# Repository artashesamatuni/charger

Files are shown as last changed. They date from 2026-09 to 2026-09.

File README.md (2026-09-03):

# Single-phase AC EVSE prototype

Engineering baseline for a European Mode 3 EV supply equipment prototype:

- 230 V AC, single phase
- 32 A maximum (7.4 kW nominal), configurable 6–32 A
- permanently attached cable with Type 2 vehicle connector (Case C)
- ESP32 controller with Wi-Fi
- IEC 61851 control pilot

Engineering documents:

- [System baseline](docs/system-baseline.md): external I/O, safety concept, self-tests, charging state machine, hardware architecture, and firmware partitioning.
- [System requirements](docs/system-requirements.md): traceable, verifiable product requirements.
- [Preliminary hazard analysis](docs/hazard-analysis.md): design FMEA and required independent safety paths.
- [Architecture and interface specification](docs/architecture-and-interfaces.md): frozen product options, subsystem partitioning, communications, UI, and schematic-sheet plan.
- [Thermal derating algorithm](docs/thermal-derating.md): sensor validation, current limiting, shutdown/recovery behavior, and environmental test matrix.\n- [Rev A controller schematic specification](hardware/rev-a/controller-schematic-spec.md): ESP32-S3, BRCS01C, watchdog, hardwired contactor inhibit, self-test, and KiCad sheet plan.\n- [Rev A preliminary BOM](hardware/rev-a/preliminary-bom.csv): selected, provisional, and open controller components.

> This repository is an engineering prototype, not certified equipment. Mains testing requires appropriate competence, isolation, protection, enclosure, and test equipment. Do not connect a vehicle or public supply until the safety circuits and fault responses have been independently reviewed and tested.

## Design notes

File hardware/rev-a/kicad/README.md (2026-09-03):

# KiCad schematic — Rev A

## Open the schematic

Open `evse-controller-rev-a.sch` in KiCad 8 or 9. It is stored in the KiCad legacy schematic format so it remains human-reviewable in GitHub. KiCad will offer to convert it; save the converted result as `.kicad_sch`.

## Current content

- protected 24 V input;
- provisional 5.5 V, 5 V RDC and 3.3 V power stages;
- ESP32-S3-WROOM-1;
- BRCS01C-05-H1 connector;
- fail-safe pull-up interpretation for both trip outputs;
- hardware safety-latch functional block;
- TPS3430-Q1 watchdog functional block;
- Type 2 CP/PP connector;
- future contactor interface, with contactor and coil driver DNP.

## Verification status

The text structure is balanced and contains 16 component blocks and 52 wire records. KiCad and ERC were not available on the authoring host, so graphical import, symbol resolution and ERC are **not yet verified**.

Do not assign PCB footprints or order a PCB from this draft. Several complex devices are represented as named functional connector blocks while their exact implementation is refined in the adjacent sheet-definition documents.

## Required KiCad review

1. Open and convert the legacy file.
2. Confirm that `RF_Module:ESP32-S3-WROOM-1` resolves with the installed symbol library.
3. Inspect power pin visibility and pin mapping.
4. Replace each named functional connector block with the final manufacturer symbol.
5. Add no-connect flags intentionally.
6. Run ERC with custom safety rules.
7. Export PDF and visually inspect every net and junction.

The contactor will be added only after its exact model and coil interface are frozen.

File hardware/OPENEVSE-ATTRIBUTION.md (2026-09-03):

# OpenEVSE design-basis attribution

Parts of the EVSE controller architecture and subsequent hardware implementation are adapted from **OpenEVSE_PLUS v6.5.1**.

- Upstream project: https://github.com/OpenEVSE/OpenEVSE_PLUS
- Reference revision inspected: repository tree `b9f101e9b7bae0846ca72638b9d22bb8c49298d5`
- Reference schematic: `OpenEVSE_PLUS_v6.5.1/OpenEVSE_PLUS_v6.5.1.sch`
- Upstream hardware license: Creative Commons Attribution-ShareAlike 3.0 (CC BY-SA 3.0)
- License text: https://creativecommons.org/licenses/by-sa/3.0/

## Functions used as a design basis

- ±12 V control-pilot generation;
- pilot ADC/state measurement;
- proximity-pilot measurement;
- residual-current/GFCI self-test pattern;
- separate relay commands and feedback/weld detection;
- current-transformer measurement;
- power-on safe defaults.

## Intentional differences

- ESP32-S3 at 3.3 V replaces ATmega328P at 5 V.
- BRCS01C-05-H1 and an external Type A RCD replace the OpenEVSE GFCI implementation.
- EU single-phase Type 2, TN-S/TN-C-S and L+N disconnection replace the North-American baseline.
- 24 VDC controller input replaces the onboard mains supply.
- An independent window watchdog and hardwired set-dominant RDC latch are added.
- CP/PP input scaling and protection are recalculated for 3.3 V.
- Contactor selection and driver are deferred.

Derived hardware files must preserve attribution and be distributed under terms compatible with CC BY-SA 3.0. This notice is not a claim that OpenEVSE has reviewed or approved this design.

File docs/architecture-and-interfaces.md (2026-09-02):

# Architecture and interface specification — revision 0.1

## 1. Frozen product decisions

| Topic | Decision |
|---|---|
| Electrical rating | 230 V AC, single phase, 32 A, 7.4 kW |
| Vehicle connection | Permanently attached cable with Type 2 plug |
| Installation systems | TN-S and TN-C-S, with separate L/N/PE supplied to the EVSE |
| Enclosures | IP20 development configuration; IP65 outdoor-target configuration |
| Mounting | Wall and pedestal |
| Environment | −25…+55 °C; maximum altitude 4000 m |
| Residual-current protection | Integrated RDC-DD function suitable for the selected conformity route |
| Upstream protection | External distribution-board MCB and Type A RCD |
| Controller | ESP32-S3 module, ESP-IDF |
| Base local UI | Status LEDs and one multifunction/service button |
| IP65 UI | Status LEDs, button, touch display, and RFID reader |
| Phone access | Responsive local web application initially |
| Wi-Fi modes | SoftAP commissioning plus station/client operation |
| Time | NTP-synchronized civil time; monotonic safety timing |
| Integration | MQTT telemetry and validated commands |

TN-C-S support means the installation presents separate L, N, and PE conductors after the upstream PEN separation point. The EVSE shall never contain a PEN link or use N as a substitute for PE.

The external C32 circuit breaker and Type A 40 A / 30 mA RCD are outside the EVSE design boundary. They shall not appear as fitted components in the EVSE schematic or BOM. The top-level schematic shall show only the L/N/PE installation interface and an off-sheet installation note. Fuses or protection dedicated solely to internal auxiliary circuits remain inside the EVSE where required.

## 2. Enclosure strategy

### IP20 development configuration

- Intended for a controlled laboratory/indoor prototype environment.
- Accessible service connectors may be fitted only where touch-safe separation is maintained.
- The high-voltage compartment remains covered and tool-accessible even though the outer development housing is IP20.
- It may expose USB/service interfaces and may carry the optional display during firmware development.

### IP65 outdoor-target configuration

- Sealed enclosure, glands, attached-cable entry, button, indicators, optional display/RFID window, and any pressure-equalization vent must form one tested ingress-protection system.
- Prefer an external-antenna ESP32-S3-WROOM-1U if the enclosure, display metallization, mounting surface, or internal power hardware materially shields a PCB antenna.
- If the PCB-antenna WROOM-1 is used, place its antenna at the enclosure/PCB edge with the Espressif keepout and validate RF performance in the complete enclosure.
- No field-accessible USB or unsealed service opening.
- Use condensation management, UV-rated materials, corrosion-resistant hardware, cable strain relief, and a drainage/orientation strategy.
- Validate both wall and pedestal installations, including gasket loading, cable pull, impact, anchoring, drainage, and antenna performance.

IP20 and IP65 are configuration targets, not labels that can be applied from component ratings alone. The assembled product needs the relevant enclosure and ingress tests.

The −25…+55 °C and 4000 m envelope is a demanding condition. Reduced air density affects cooling, and electrical clearances require altitude correction above 2000 m. Automatic current derating is explicitly permitted, so 32 A is available only inside the validated thermal envelope. The final rating label and manual shall state the applicable derating behavior.

## 3. Controller selection

Use **ESP32-S3-WROOM-1-N8R8** as the prototype baseline, subject to availability and schematic pin audit. Its flash/PSRAM combination provides margin for two OTA images, HTTPS, web assets, MQTT, logs, and an optional graphical display. Using a module reduces RF-design risk relative to a bare SoC.

For a difficult IP65 RF environment, use the **ESP32-S3-WROOM-1U** antenna variant and a suitable certified 2.4 GHz antenna/feedthrough. Final suffix and temperature grade must be checked against the current Espressif ordering table before procurement.

Controller design rules:

- Four-layer controller PCB preferred, with a continuous ground plane.
- Maintain the module antenna keepout; keep high-current, CP, coil, USB, and fast digital traces away from it.
- Keep the controller in SELV. All mains measurements and non-SELV external interfaces cross rated isolation/protection barriers.
- Use an external supervisor/safety gate; internal ESP32 watchdogs alone are not the final contactor enable.
- Reserve native USB for IP20 development; protect against ESD and restrict it in production.

## 4. Functional partitioning

| Block | Primary ESP32-S3 interface | Isolation/safety notes |
|---|---|---|
| CP generator | PWM/timer plus enable | Protected ±12 V analog domain; defined power-up behavior |
| CP measurement | ADC plus comparators/capture | Independent plausibility signals and input protection |
| PP measurement | ADC | Protected against connector ESD/shorts |
| RDC-DD | latched fault input, test output, optional diagnostics | Fault also directly disables the coil gate |
| Contactor driver | request plus retriggered safety enable | Defaults off; controlled coil transient path |
| Contactor feedback | isolated auxiliary and output-voltage sense | Diverse weld/failure observations |
| Energy meter | isolated UART/SPI or pulse outputs | Display-grade baseline; billing grade not claimed |
| Temperature | protected ADC channels | Power termination/contactor and PCB minimum |
| LEDs/button | GPIO/PWM and protected input | No shared safety-enable pins |
| Touch display | optional SPI plus I2C/SPI touch | SELV, keyed/protected daughterboard connector |
| RFID | optional SPI/I2C plus interrupt | Identifier only; no direct actuator authority |
| Service | USB and/or isolated UART | IP20/service mode only |

## 5. RDC-DD selection specification

Select a certified/integrable RDC-DD or RDC-MD explicitly intended for Mode 3 EVSE and supported by conformity documentation. The selection review shall record:

- IEC 62955 claim and exact function class;
- AC residual-current and 6 mA DC behavior required by the selected topology;
- current aperture/conductor arrangement for L and N;
- test-input behavior, startup time, trip/reset behavior, tolerances, and diagnostic coverage;
- fail-safe response to supply loss, open sensor, internal fault, or broken communication;
- hardware output suitable for direct contactor-disable gating;
- isolation, creepage/clearance, temperature, EMC, and lifecycle data;
- required upstream Type A RCD and installation instructions.

Do not implement the protective function using an uncertified current transformer plus firmware ADC thresholds. A separate measurement channel may log residual current, but it is not the trip path.

## 6. User interface

LED patterns must remain distinguishable without relying only on color:

| State | Indication concept |
|---|---|
| Boot/self-test | short sequenced pulse |
| Available | slow green pulse |
| Vehicle connected | steady blue |
| Charging | moving/pulsing blue or green |
| Suspended | double pulse |
| Recoverable inhibit | amber pattern |
| Latched safety fault | persistent red coded flashes |
| Commissioning AP | distinct white/blue pattern |

Button behavior:

- Short press: wake status/UI or request a policy-controlled start/stop.
- Long press: enter commissioning AP only while not charging.
- Very long/service action: configuration reset with physical presence; do not silently erase safety evidence.
- Apply hardware/firmware debounce and stuck-button detection.

The IP65 product includes the display and RFID. The display may show state, limit, current, power, energy, network, time, and faults. RFID submits an authorization token to the policy service. Use a sealed UI daughterboard so the safety/power PCB remains independent. Energy values are for indication and statistics, not billing/MID use.

The selected attached Type 2 cable has no plug temperature sensor. Thermal protection shall therefore monitor internal high-risk terminations, contactor/power conductors, and PCB temperature, and the cable/plug shall be a qualified 32 A assembly with suitable margin.

## 7. Network behavior

### SoftAP provisioning

1. First boot or a deliberate physical-presence action enters SoftAP provisioning.
2. Generate a device-unique SSID and require a device-unique secret or proof of possession; do not use one universal password.
3. Serve the local configuration UI and protect state-changing requests against unauthorized clients and cross-site requests.
4. Provision station credentials, locale/time zone, NTP, MQTT, and the site current limit.
5. Leave provisioning after success or timeout; never expose an indefinite open AP.
6. Re-entry requires a local button action with the contactor open.

### Station/client mode

- Connect to the configured 2.4 GHz WLAN using bounded exponential reconnects.
- Continue safe local charging during network loss if authorization policy permits.
- Provide HTTPS on the LAN where feasible. Prototype HTTP must be restricted to a trusted local network and must not carry reusable cloud secrets.
- Optional mDNS discovery is a convenience, not a dependency.

### Time

- NTP supplies civil timestamps, schedules, certificate checks, and log correlation.
- CP debounce, contactor transitions, watchdogs, trip response, retries, and session sequencing use monotonic timers.
- Before time is valid, logs are marked unsynchronized and an explicit schedule policy applies; clock jumps cannot extend safety deadlines.

## 8. MQTT v1 contract

Use a configurable root such as `evse/<device_id>/v1/`:

| Topic suffix | Direction | Retain | Purpose |
|---|---|---:|---|
| `availability` | publish | yes | Online/offline with broker last-will |
| `state` | publish | yes | EVSE, CP, session, and authorization state |
| `telemetry` | publish | no | Voltage, current, power, temperature, CP/PP diagnostics |
| `energy` | publish | yes | Session and lifetime counters |
| `fault` | publish | yes | Active/latched fault and first-fault summary |
| `config/reported` | publish | yes | Non-secret effective configuration |
| `cmd/request` | subscribe | no | Versioned command envelope |
| `cmd/response` | publish | no | Correlation ID, result, and rejection reason |
| `config/set` | subscribe | no | Bounded non-safety settings/limits |

Commands require a schema version, unique correlation ID, name, parameters, and optional expiry. Reject duplicates, stale messages when trusted time exists, out-of-range values, invalid states, and requests conflicting with local safety. Never publish credentials or private keys.

Initial commands: `authorize`, `stop`, `set_current_limit`, and `clear_recoverable_fault`. Severe latched faults cannot be remotely cleared. MQTT over TLS is the normal mode; plaintext MQTT is an explicit local-development option only.

## 9. Software authority

```mermaid
flowchart TB
  UI[LED/button/display/RFID] --> Policy[Authorization and policy]
  Web[Local web UI] --> Policy
  MQTT[MQTT client] --> Policy
  Policy --> SM[Charging state machine]
  Limits[Limit manager] --> SM
  CP[CP/PP service] --> SM
  Meter[Meter/thermal service] --> Limits
  SM --> Request[Contactor request]
  Safety[Safety supervisor] --> Gate[Hardware safety gate]
  Request --> Gate
  Gate --> Coil[Contactor coil]
  RDC[RDC-DD hardware fault] --> Gate
  Watchdog[External supervisor] --> Gate
```

The web UI, MQTT, RFID, and button create requests; none owns an actuator.

## 10. Schematic sheet plan

| Sheet | Contents |
|---:|---|
| 01 | Hierarchy, connectors, net classes, safety-domain boundaries |
| 02 | L/N/PE installation interface, surge/EMI as required, internal auxiliary protection, and power distribution; external C32/Type A RCD shown only by note |
| 03 | Two-pole contactor, coil supply/driver, auxiliary contact |
| 04 | Isolated input/output voltage sensing and metering |
| 05 | RDC-DD, test circuit, and direct trip chain |
| 06 | CP ±12 V generator, PWM, measurement, diode detection, PP |
| 07 | Isolated AC/DC supply, low-voltage rails, supervision |
| 08 | ESP32-S3, boot/reset, USB/service, external watchdog |
| 09 | LEDs, button, temperatures, display/RFID expansion |
| 10 | Protection, test points, programming/manufacturing interface |

## 11. Inputs required for final component selection

1. SPD assumptions, maximum prospective fault current, and installation-coordination notes; the external C32 and Type A 40 A / 30 mA RCD are not EVSE schematic/BOM components.
2. Touch-display size/interface and RFID technology/credential policy.
3. Enclosure material, mounting dimensions, and pedestal mechanical requirements.
4. Overvoltage category, pollution degree, and insulation-system assumptions for the 4000 m design.
5. Measured thermal limits needed to finalize the derating curve for each enclosure/mounting configuration.

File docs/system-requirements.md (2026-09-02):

# System requirements — revision 0.1

## 1. Conventions

- **Shall** indicates a mandatory, verifiable requirement.
- Verification methods: **I** inspection, **A** analysis, **T** test, **D** demonstration.
- Status **Allocated** means the requirement has an identified implementation owner but is not yet verified.
- Normative values and timings marked **TBD-N** must be taken from licensed standards before design release.

## 2. Product and rating requirements

| ID | Requirement | Allocation | Verify | Status |
|---|---|---|---|---|
| PR-001 | The EVSE shall provide IEC 61851 Mode 3 AC charging through a permanently attached cable with a Type 2 vehicle connector. | System | I/T | Allocated |
| PR-002 | The EVSE shall operate from 230 V AC nominal, 50 Hz, single-phase L/N/PE supply. | Power | T | Allocated |
| PR-003 | The EVSE shall have a rated continuous output current of 32 A and nominal power of 7.4 kW. | Power/thermal | A/T | Allocated |
| PR-004 | The configured charging-current range shall be 6–32 A. | Firmware/CP | T | Allocated |
| PR-005 | The product shall default to output de-energized on startup, reset, brownout, firmware failure, or loss of auxiliary power. | Safety hardware | A/T | Allocated |
| PR-006 | Wi-Fi availability shall not be required to execute a safety shutdown. | Architecture | I/T | Allocated |
| PR-007 | The common electronics shall support an IP20 development configuration and an IP65 outdoor-target configuration. | Mechanical/system | I/T | Allocated |
| PR-008 | The EVSE shall support TN-S and TN-C-S installations in which separate L, N, and PE conductors are presented at the EVSE input. | Installation/electrical | I/T | Allocated |
| PR-009 | The EVSE shall not accept or perform a PEN split; TN-C-S PEN separation shall occur upstream in accordance with applicable installation rules. | Installation/electrical | I | Allocated |
| PR-010 | The EVSE shall operate over an ambient-temperature range of −25 °C to +55 °C. | System/thermal | T | Allocated |
| PR-011 | The EVSE shall be designed for installation altitude up to 4000 m. | Electrical/thermal | A/T | Allocated |
| PR-012 | The IP65 configuration shall support wall and pedestal mounting without compromising ingress protection, cooling, cable strain relief, or user access. | Mechanical | I/T | Allocated |

## 3. Power-path requirements

| ID | Requirement | Allocation | Verify | Status |
|---|---|---|---|---|
| PW-001 | Both L and N supplied to the vehicle shall be opened by the power contactor. | Contactor | I/T | Allocated |
| PW-002 | PE shall not be switched and shall remain bonded from input to cable PE. | Wiring/enclosure | I/T | Allocated |
| PW-003 | All conductors, terminals, cable assemblies, contacts, and protection devices in the charging path shall be rated for at least 32 A continuous duty under worst-case enclosure temperature and installation conditions. | Electrical/thermal | I/A/T | Allocated |
| PW-004 | The contactor shall be rated for the applicable utilization category, prospective fault current, switching endurance, coil voltage, and operating temperature. | Electrical | I/A | Open |
| PW-005 | The design shall independently sense input supply presence and vehicle-side output voltage with suitable isolation. | Sensing | I/T | Allocated |
| PW-006 | The design shall obtain contactor mechanical state through a positively linked/appropriate auxiliary contact or an equivalently justified diagnostic arrangement. | Contactor | I/A/T | Open |
| PW-007 | Unexpected voltage on the vehicle output while the contactor is commanded open shall inhibit charging and latch a welded/stuck-contactor fault. | Safety/firmware | T | Allocated |
| PW-008 | Failure to observe contactor closure within the specified transition time shall cause the coil command to be removed and a fault recorded. | Safety/firmware | T | Allocated |
| PW-009 | Surge, overcurrent, auxiliary-circuit fusing, and EMC protection shall be coordinated with the installation and component ratings. | Power entry | I/A/T | Open |
| PW-010 | The installation shall provide the coordinated branch MCB and Type A RCD in an external distribution board. | Installation | I | Allocated |
| PW-011 | Product installation instructions shall state the required upstream MCB, Type A RCD, SPD/overvoltage assumptions, conductor sizes, and prospective fault-current limits. | Installation/electrical | I/A | Open |
| PW-012 | The external C32 circuit breaker and Type A 40 A / 30 mA RCD shall be excluded from the EVSE schematic and BOM; only the L/N/PE boundary and installation requirement shall be documented. | System/electrical | I | Allocated |

## 4. Control-pilot and proximity requirements

| ID | Requirement | Allocation | Verify | Status |
|---|---|---|---|---|
| CP-001 | The EVSE shall generate the IEC 61851 control pilot with nominal ±12 V levels and 1 kHz PWM where applicable. | CP hardware | T | Allocated |
| CP-002 | CP voltage, frequency, duty cycle, source impedance, rise/fall characteristics, tolerances, and transition timing shall meet the controlled edition of IEC 61851-1. | CP hardware/firmware | T | TBD-N |
| CP-003 | The EVSE shall distinguish stable CP states A, B, C, D, E, and F using thresholds, debounce, and timing compliant with IEC 61851-1. | CP firmware | T | TBD-N |
| CP-004 | The EVSE shall verify the vehicle diode signature before energizing the power contactor. | CP hardware/firmware | T | Allocated |
| CP-005 | State D shall not energize the contactor because forced ventilation is not supported. | State machine | T | Allocated |
| CP-006 | The EVSE shall measure PP and shall never advertise more current than the cable assembly permits. | PP/limit manager | T | Allocated |
| CP-007 | An open, shorted, implausible, or uncalibrated PP measurement shall inhibit charging. | PP/limit manager | T | Allocated |
| CP-008 | For 6–51 A advertisement, the firmware shall encode current using the applicable IEC 61851 PWM relationship and shall verify the generated duty cycle by measurement. | CP firmware/hardware | T | Allocated |
| CP-009 | When the allowable current is below 6 A, the EVSE shall suspend charging using standards-compliant pilot behavior and shall not advertise a sub-6 A current. | State machine | T | Allocated |
| CP-010 | CP loss, short, invalid plateau, invalid diode result, or commanded/measured PWM disagreement shall prevent or terminate power delivery. | Safety/CP | T | Allocated |

## 5. Electrical-protection requirements

| ID | Requirement | Allocation | Verify | Status |
|---|---|---|---|---|
| SF-001 | Residual-current protection shall be implemented using a conformity-appropriate arrangement for EU Mode 3 EVSE. | Protection architecture | I/A/T | Open |
| SF-002 | If Type A upstream RCD coordination is selected, the EVSE shall use an IEC 62955-compliant RDC-DD providing the required 6 mA DC detection function. | Certified module | I/T | Open |
| SF-003 | A residual-current trip shall remove contactor coil energy through a safety path that does not depend solely on the ESP32 application. | Safety hardware | I/T | Allocated |
| SF-004 | The RDC-DD/RCM test function shall be exercised at startup and at the interval required by the chosen device and applicable standard. | Safety hardware/firmware | I/T | Open |
| SF-005 | A failed residual-current self-test shall inhibit charging and latch a fault. | Safety supervisor | T | Allocated |
| SF-006 | Isolation, creepage, clearance, insulation, and protective bonding shall be calculated for the final overvoltage category, pollution degree, material group, altitude, and enclosure. | PCB/mechanical | I/A/T | Open |
| SF-007 | Accessible SELV and network circuitry shall have the required isolation from mains, contactor-coil transients, and CP fault conditions. | Electrical/PCB | I/T | Allocated |
| SF-008 | The enclosure shall prevent access to hazardous live parts in normal use and foreseeable single-fault conditions. | Mechanical | I/T | Open |
| SF-009 | Safety-critical protective functions shall be evaluated for single faults and common-cause failures before schematic release. | Safety analysis | A | Allocated |
| SF-010 | The EVSE shall incorporate an IEC 62955-conformity-appropriate RDC-DD function and expose its fault and test results to the safety supervisor. | Certified RDC-DD/safety | I/T | Allocated |
| SF-011 | The RDC-DD fault output shall participate in the independent hardware contactor-disable chain. | Safety hardware | I/T | Allocated |
| SF-012 | The IP65 configuration shall maintain its ingress-protection target with the cable, glands, vents, display/RFID windows, buttons, and service closures installed. | Mechanical | I/T | Open |
| SF-013 | Creepage, clearance, insulation coordination, component voltage ratings, and dielectric verification shall account for operation at 4000 m, including the applicable altitude correction above 2000 m. | Electrical/PCB | A/I/T | Open |

## 6. Thermal and measurement requirements

| ID | Requirement | Allocation | Verify | Status |
|---|---|---|---|---|
| TM-001 | Temperature shall be measured at the highest-risk power termination/contactor region and on the control PCB. | Thermal/electrical | I/T | Allocated |
| TM-002 | Temperature sensors shall be diagnosed for open circuit, short circuit, stuck reading, and implausible rate of change where technically feasible. | Firmware | T | Allocated |
| TM-003 | The EVSE shall progressively derate advertised current before reaching the shutdown threshold. | Limit manager | T | Allocated |
| TM-004 | Exceeding the shutdown threshold or losing a required temperature sensor shall stop charging. | Safety supervisor | T | Allocated |
| TM-005 | Derating, shutdown, and restart thresholds shall be derived from measured component and enclosure temperature rise with margin. | Thermal | A/T | Open |
| TM-006 | The product shall apply a validated automatic current-derating curve whenever thermal conditions do not permit 32 A continuous operation. | Thermal/system | A/T | Allocated |
| TM-007 | Thermal derating shall only maintain or reduce the currently permissible advertised current; it shall never override a lower product, cable, site, user, or backend limit. | Limit manager | T | Allocated |
| TM-008 | If the thermally permissible current falls below 6 A, the EVSE shall suspend charging using standards-compliant pilot behavior and open the contactor. | State machine | T | Allocated |
| TM-009 | Thermal current increases shall be rate limited and require a stable cooldown interval; safety-related reductions and shutdowns shall not be delayed by that rate limit. | Thermal/limit manager | T | Allocated |
| TM-010 | A missing, stale, open, shorted, or implausible mandatory thermal sensor shall prevent charging or apply a separately justified fail-safe limit. | Safety supervisor | T | Allocated |
| TM-011 | Thermal shutdown shall latch for the charging session and shall not automatically resume until all relevant sensors remain below validated restart thresholds for a defined cooldown time. | State machine | T | Allocated |
| ME-001 | Voltage, current, power, and cumulative energy shall be measured for diagnostics and user display. | Metering | T | Allocated |
| ME-002 | Metering accuracy shall not be represented as billing-grade unless the complete measurement and conformity pathway supports that claim. | Product | I | Allocated |
| ME-003 | Energy metering in revision 0.1 shall be intended for indication, diagnostics, and statistics only; MID/billing conformity is out of scope. | Product/metering | I/T | Allocated |

## 7. Control and software requirements

| ID | Requirement | Allocation | Verify | Status |
|---|---|---|---|---|
| SW-001 | Only the charging state machine may request contactor closure; only the safety supervisor may provide the final hardware enable. | Architecture | I/T | Allocated |
| SW-002 | The advertised current shall be the minimum of product, PP cable, site, thermal, load-management, and user/backend limits. | Limit manager | T | Allocated |
| SW-003 | Every actuator command shall be range-checked and validated against current state and safety conditions. | Firmware | I/T | Allocated |
| SW-004 | Task and hardware watchdogs shall force the output to a de-energized condition when safety-related execution deadlines are missed. | Firmware/hardware | T | Allocated |
| SW-005 | Safety inputs shall include freshness, range, and plausibility status; stale or invalid mandatory inputs shall inhibit charging. | Firmware | T | Allocated |
| SW-006 | Fault processing shall preserve the first fault cause and a snapshot of safety-relevant measurements and state. | Diagnostics | T | Allocated |
| SW-007 | Safety-related configuration shall be versioned, bounded, integrity checked, and replaced with a no-charge or conservative state when invalid. | Configuration | T | Allocated |
| SW-008 | No network command shall directly control the contactor GPIO or bypass the state machine. | Architecture | I/T | Allocated |
| SW-009 | The device shall continue safe local operation during Wi-Fi loss according to the configured authorization policy. | Firmware | T | Allocated |
| SW-010 | Firmware updates shall only begin with the contactor open and charging unavailable. | Update manager | T | Allocated |
| SW-011 | OTA shall use authenticated images, an A/B or equivalent recovery design, and automatic rollback after failed boot validation. | Bootloader/update | I/T | Allocated |
| SW-012 | Production configuration shall consider secure boot, flash encryption, credential protection, disabled debug paths, and TLS identity provisioning. | Security | I/A/T | Open |
| SW-013 | The controller shall use an ESP32-S3 module and ESP-IDF. | Controller | I | Allocated |
| SW-014 | The EVSE shall provide a protected Wi-Fi SoftAP commissioning mode with a local web configuration interface. | Network/UI | D/T | Allocated |
| SW-015 | The EVSE shall operate as a Wi-Fi station after provisioning and shall provide the local web interface on the configured LAN. | Network/UI | D/T | Allocated |
| SW-016 | Loss of station connectivity shall not automatically erase credentials or continuously expose an unsecured commissioning AP. | Network/security | T | Allocated |
| SW-017 | The device shall synchronize civil time through configurable NTP servers, while all safety deadlines and sequencing use monotonic timers independent of NTP. | Time service | T | Allocated |
| SW-018 | MQTT integration shall support telemetry, availability, commands, and configuration through a versioned topic and payload schema. | MQTT | D/T | Allocated |
| SW-019 | MQTT commands shall be authenticated by the transport/configuration policy, range checked, acknowledged, and passed through the normal state machine. | MQTT/security | T | Allocated |
| SW-020 | MQTT over TLS shall be the default for non-local or untrusted networks; plaintext MQTT shall require an explicit local-development setting. | MQTT/security | I/T | Allocated |

## 8. User and service requirements

| ID | Requirement | Allocation | Verify | Status |
|---|---|---|---|---|
| UI-001 | The EVSE shall visibly distinguish unavailable, available, vehicle connected, charging, suspended, and faulted states. | UI | D/T | Allocated |
| UI-002 | A latched safety fault shall not be remotely cleared unless the specific hazard analysis explicitly permits it. | UI/network | T | Allocated |
| UI-003 | A welded-contactor or residual-current fault shall require the defined local/service recovery procedure. | Service | D/T | Allocated |
| UI-004 | Service diagnostics shall expose state, first-fault code, measurements, firmware/hardware versions, reset cause, and self-test results without exposing credentials. | Diagnostics | D/T | Allocated |
| UI-005 | The base user interface shall provide status LEDs and one local button. | UI hardware | D/T | Allocated |
| UI-006 | Button actions shall be time-qualified and state dependent; no button action may directly energize the contactor. | UI/firmware | T | Allocated |
| UI-007 | The architecture shall provide optional isolated/SELV interfaces for a touch display and RFID reader without changing safety authority. | UI hardware | I/T | Allocated |
| UI-008 | Phone configuration and control shall initially be available through a responsive local web interface; packaging it as a PWA or native app is a later product decision. | Web UI | D | Allocated |
| UI-009 | The IP65 configuration shall include status LEDs, a local button, RFID, and a touch display. | UI/mechanical | I/D/T | Allocated |
| UI-010 | The display, RFID window/antenna, and button integration shall preserve the assembled IP65 rating and required impact/environmental performance. | UI/mechanical | I/T | Open |
| UI-011 | The design shall not depend on a temperature sensor embedded in the attached Type 2 plug. | System | I | Allocated |

## 9. Verification gates

| Gate | Exit criteria |
|---|---|
| G0 Architecture | Product options frozen; requirements and hazard analysis reviewed |
| G1 Low-voltage prototype | CP/PP simulator passes all states/faults; no mains connected |
| G2 Power prototype | protected fixture verifies switching, sensing, RCM, watchdog, and thermal faults |
| G3 Vehicle test | independent safety review complete; controlled vehicle charging at limited then full current |
| G4 Pre-compliance | electrical safety, EMC, thermal, environmental, and abnormal-operation tests completed |

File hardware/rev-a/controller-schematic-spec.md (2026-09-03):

# Controller schematic specification — Rev A / Draft 0.1

> Safety-critical draft. This document is a connectivity specification for schematic capture, review, and bench validation. It is not approved for connection to mains or a vehicle.

## 1. Scope of this revision

Detailed sheet definitions are now maintained under `hardware/rev-a/schematic/`. The contactor itself and its coil-specific driver are postponed; J_K1 defines their interface.

This first schematic increment covers:

- ESP32-S3 controller core;
- 24 V, 5 V, and 3.3 V low-voltage power tree;
- BITUO BRCS01C-05-H1 residual-current sensor interface;
- independent contactor-coil inhibit path;
- external window watchdog;
- contactor command and auxiliary feedback;
- local reset, service USB, status LEDs, and button.

CP/PP analog circuitry, isolated mains sensing, energy metering, display, and RFID are reserved for the following schematic increments.

## 2. Safety architecture

The power contactor is normally open. Its 24 VDC coil may be energized only when every independent permission is true:

```text
COIL_ENABLE =
    MCU_CONTACTOR_REQUEST
    AND WATCHDOG_OK
    AND RDC_POWER_OK
    AND NOT RDC_DC_TRIP
    AND NOT FAULT_LATCHED
```

The `RDC_DC_TRIP` signal has a direct hardware path that clamps the contactor MOSFET gate low. ESP32 firmware is not required to open the contactor after an RDC fault.

The ESP32 observes all safety signals for diagnostics, but software cannot override an asserted hardware inhibit.

## 3. Power domains

| Net | Nominal | Source | Loads | Notes |
|---|---:|---|---|---|
| `+24V_ISO` | 24 VDC | certified isolated AC/DC PSU | contactor coil, 5.5 V preregulator | PSU selection pending 4000 m review |
| `+5V_PRE` | 5.4–5.6 V | buck from 24 V | RDC low-noise LDO, 3.3 V regulator | allows LDO regulation margin |
| `+5V_RDC` | 5.00 V ±3% | dedicated low-noise LDO | BRCS01C only | ripple target below 150 mV |
| `+3V3` | 3.3 V | regulator from 5V_PRE | ESP32-S3 and logic | supervised |
| `GND_SELV` | 0 V | isolated PSU secondary | controller reference | PE connection strategy remains open |
| `PE` | protective earth | installation | Type 2 PE and enclosure bonding | never switched; not signal ground by default |

Do not connect `GND_SELV` to PE until the CP isolation/reference architecture is frozen and reviewed.

## 4. Main devices

| Ref | Selected device | Function | Status |
|---|---|---|---|
| U1 | ESP32-S3-WROOM-1-N8R8 | application controller and Wi-Fi | selected |
| U2 | TPS3430-Q1 | independent window watchdog | selected for draft |
| U3 | BRCS01C-05-H1 | 6 mA DC / 30 mA AC+DC residual-current sensor | preferred, certification evidence pending |
| U4 | TPS54360B, configured for 5.5 V | low-voltage preregulator | provisional; compensation calculation pending |
| U5 | TLV76750 or qualified equivalent | dedicated 5 V RDC LDO | provisional |
| U6 | TPS62133, configured for 3.3 V | ESP32 supply | provisional; power calculation pending |
| U7 | logic/supervisor block | power-good and safety gating | implementation pending review |
| Q1 | DNP in controller-only increment | future contactor driver | postponed until coil selection |
| Q2 | small-signal NPN/N-MOSFET | direct RDC gate clamp | provisional topology |
| D1 | DNP in controller-only increment | future coil suppression | postponed until coil selection |
| K1 | Baomain BMHC7-40, 2NO, DC/AC 24 V coil | L/N switching | preferred prototype candidate; conditional |

## 5. ESP32-S3 core connections

### 5.1 Mandatory module connections

- All U1 3.3 V pins connect to `+3V3` with local 100 nF capacitors and bulk capacitance per the current Espressif module guidance.
- All grounds connect to a continuous `GND_SELV` plane.
- `EN` has the Espressif-recommended RC reset network and a service reset pushbutton.
- Boot-strapping pins receive explicit safe pull resistors; no safety actuator is assigned to a strapping pin.
- Native USB D+/D− route as a 90 Ω differential pair to an ESD-protected IP20 service connector.
- The RF antenna is placed at the PCB edge with the manufacturer keepout. The IP65 variant may use WROOM-1U and an external antenna.
- Contactor and safety outputs have external pull-down/off states independent of ESP32 reset.

### 5.2 Provisional GPIO allocation

| Signal | Direction | Provisional GPIO | Power-up state | Notes |
|---|---:|---:|---|---|
| `CONTACTOR_REQUEST` | out | GPIO4 | pulled low | request only; not final coil drive |
| `WATCHDOG_WDI` | out | GPIO5 | low/static | serviced only by safety supervisor task |
| `RDC_TEST_CMD` | out | GPIO6 | inactive | transistor/buffered into U3 TEST |
| `RDC_DC_TRIP_SENSE` | in | GPIO7 | external defined state | readback only |
| `RDC_ACDC_TRIP_SENSE` | in | GPIO8 | external defined state | diagnostic/additional shutdown candidate |
| `FAULT_LATCH_SENSE` | in | GPIO9 | defined | read hardware latch state |
| `CONTACTOR_AUX` | in | GPIO10 | defined | isolated/protected input |
| `COIL_CURRENT_OK` | in | GPIO11 | defined | optional comparator |
| `STATUS_LED_DATA` | out | GPIO12 | off | never shares safety pins |
| `LOCAL_BUTTON` | in | GPIO13 | pulled | protected/debounced |
| `I2C_SDA` | I/O | GPIO17 | pulled up | sensors/UI expansion |
| `I2C_SCL` | out | GPIO18 | pulled up | sensors/UI expansion |
| `UART_TX_SERVICE` | out | GPIO43 | idle | IP20 service |
| `UART_RX_SERVICE` | in | GPIO44 | pulled | IP20 service |

GPIO allocation remains provisional until CP/PP, metering, display, RFID, PSRAM constraints, and module strapping are checked together.

## 6. BRCS01C-05-H1 interface

### 6.1 Connector J3

Use a keyed, locking six-position connector. Pin numbers shall match the exact ordered cable assembly and manufacturer drawing before release.

| J3 signal | BRCS01C-05 function | Controller connection |
|---|---|---|
| `RDC_VCC` | VCC | `+5V_RDC` through ferrite bead and local decoupling |
| `RDC_ACDC_TRIP` | Type A 30 mA AC or 6 mA DC trip | protected hardware input and ESP32 sense |
| `RDC_GND` | GND | `GND_SELV` |
| `RDC_CAL` | calibration/manufacturing function | test pad or controlled circuit; exact use pending datasheet |
| `RDC_TEST` | self-test command | buffered output from `RDC_TEST_CMD` |
| `RDC_DC_TRIP` | 6 mA DC trip | direct gate clamp, fault latch, and ESP32 sense |

Manufacturer documentation indicates that the 5 V version requires 4.85–5.15 V and recommends filtering close to the sensor. Exact output drive, logic thresholds, self-test timing, and CAL behavior must be verified against the supplied production datasheet.

### 6.2 Primary conductor routing

- Pass both L and N through the sensing aperture in the same physical direction.
- Do not pass PE through the aperture.
- Keep L and N adjacent and mechanically secured so conductor movement does not alter performance.
- Do not use the sensor body to support conductor weight.
- Respect bend radius and insulation; verify the conductor bundle fits the 17 mm aperture at the selected conductor cross-section.
- Locate the sensor before the 2-pole contactor unless the manufacturer's certified application explicitly requires another position.

## 7. Direct RDC shutdown path

### 7.1 Required behavior

1. A valid `RDC_DC_TRIP` shall turn Q1 off without firmware action.
2. The event shall set a hardware fault latch.
3. The latch shall remain asserted after the residual current disappears.
4. ESP32 reset, Wi-Fi commands, or a stuck-high `CONTACTOR_REQUEST` shall not clear it.
5. Clearing is allowed only with the contactor confirmed open, vehicle-side voltage absent, and an explicit local/service reset sequence.
6. Loss of `+5V_RDC` or invalid RDC self-test shall prevent Q1 from turning on.

### 7.2 Draft transistor path

- Q1 is the low-side contactor-coil MOSFET; its gate has a permanent gate-source pull-down.
- The normal gate drive is supplied only through the safety-enable chain.
- Q2 is connected as a dominant gate clamp: when `RDC_DC_TRIP` asserts, Q2 pulls Q1 gate to source.
- Size the Q2 input network from the measured guaranteed U3 output levels, not typical values.
- Add a hardware latch driven by the conditioned trip signal. Do not rely on an ESP32 GPIO to preserve the fault.
- Provide test points for raw trip, conditioned trip, latched fault, watchdog output, Q1 gate, and coil return.

This topology remains DRAFT until the BRCS01C output polarity and guaranteed voltage/current limits are confirmed. No PCB shall be ordered from an assumed polarity.

## 8. Watchdog and power supervision

U2 TPS3430-Q1 runs from `+3V3` and monitors `WATCHDOG_WDI`.

- Configure a window that cannot be correctly serviced by a permanently high, permanently low, too-fast, or stalled GPIO.
- `WDO_N` directly removes the safety-enable path and also resets or interrupts U1.
- The firmware safety task alone owns WDI.
- Do not service WDI from a timer ISR that can continue while the application state machine is dead.
- Startup state is contactor inhibited until the watchdog, power rails, RDC self-test, CP self-test, and contactor-open feedback are all valid.

Provide independent power-good signals for `+24V_ISO`, `+5V_RDC`, and `+3V3`. The coil driver remains off while any mandatory rail is outside its validated range.

## 9. Contactor driver

> K1 interface remains conditional. Use the BMHC7-40 variant with 2NO main contacts and a DC/AC 24 V electronic coil. The seller states 2 W maximum coil power. Q1 may switch its 24 VDC supply only after coil polarity, startup current, turn-off transient, minimum pickup voltage, and the manufacturer's permitted suppression method are verified on the purchased unit. Do not assume that an external flyback diode is suitable for the internal AC/DC coil electronics.

### 9.1 Interface J4

| Pin | Net | Description |
|---:|---|---|
| 1 | `+24V_ISO` | coil positive |
| 2 | `COIL_LOW` | switched return through Q1 |
| 3 | `AUX_COM` | auxiliary-contact common |
| 4 | `AUX_NO` | auxiliary closed indication |

### 9.2 Design requirements

- Q1 VDS rating: at least 60 V, subject to transient calculation.
- Q1 continuous/pulsed current: at least twice the worst hot coil current with SOA margin.
- Gate defaults off with U1 absent, unpowered, booting, or reset.
- Coil suppression uses a diode/TVS or zener clamp selected to meet both Q1 avalanche margin and required contactor drop-out time.
- A plain flyback diode shall not be accepted until welded-contact detection and required opening time are shown to tolerate its slower release.
- Sense coil current or at minimum detect driver/open-coil plausibility.
- Auxiliary feedback is protected and conditioned; it cannot energize Q1.

## 10. RDC self-test sequence

Before every contactor closure:

1. Confirm K1 auxiliary reports open and vehicle-side voltage sensing reports de-energized.
2. Confirm `+5V_RDC` is valid.
3. Confirm neither trip output is active.
4. Assert `RDC_TEST_CMD` using the polarity and duration specified by BITUO.
5. Require the expected trip transition inside the specified test window.
6. Require the hardware inhibit/latch path to block Q1.
7. Deassert TEST and require correct recovery of the raw output.
8. Clear the test latch only through the controlled safe reset path.
9. If any transition is absent, late, stuck, or contradictory, latch `RDC_SELF_TEST_FAILED` and prohibit charging.

Production test shall additionally inject calibrated residual-current waveforms through a separate test conductor and verify the complete sensor-to-contactor response time.

## 11. Sheet hierarchy for KiCad

| Sheet | File | Content |
|---:|---|---|
| 00 | `evse-controller.kicad_sch` | hierarchy and external connectors |
| 01 | `mcu.kicad_sch` | ESP32-S3, USB, boot/reset, service |
| 02 | `lv-power.kicad_sch` | 24 V input, buck, 5 V RDC, 3.3 V, supervisors |
| 03 | `rdc-safety.kicad_sch` | BRCS01C connector, trip conditioning, latch |
| 04 | `contactor.kicad_sch` | safety AND, Q1 driver, suppression, auxiliary input |
| 05 | `ui-basic.kicad_sch` | LEDs and button |
| 06 | `cp-pp.kicad_sch` | reserved next increment |
| 07 | `mains-metering.kicad_sch` | reserved next increment |
| 08 | `display-rfid.kicad_sch` | reserved next increment |

## 12. Blocking data before electrical release

- BITUO quotation, controlled datasheet, exact variant suffix, connector/cable drawing, and certificate/test evidence for BRCS01C-05-H1.
- Guaranteed polarity and electrical limits of DC TRIP, AC+DC TRIP, TEST, and CAL.
- Controlled BMHC7-40 datasheet and exact 2NO / DC/AC 24 V order code: pickup and dropout voltage, startup and steady-state current, permitted suppression, opening time, terminal conductor range/torque, electrical endurance, certifications, and altitude derating.
- Confirm a manufacturer-approved auxiliary contact compatible with this exact BMHC7 body. Output-voltage sensing remains mandatory and is not treated as equivalent to a mechanically linked mirror contact.
- Certified isolated AC/DC PSU rated for −25…+55 °C and 4000 m.
- Insulation coordination inputs: overvoltage category, pollution degree, material group, and required impulse voltage.
- Decision on whether AC+DC TRIP is part of the hardwired shutdown OR-chain or diagnostics only.

## 13. K1 candidate decision — Baomain BMHC7-40

- Preferred prototype configuration: `BMHC7-40`, `2NO`, `DC/AC 24 V`. Do not order the 2NC or 1NO+1NC versions for switching L and N.
- Published seller data: `Ue 250 VAC`, `Ui 500 V`, `AC-7a 40 A`, `AC-7b 18 A`, maximum coil power 2 W, operating temperature −5…+60 °C, pollution degree 2, IP20 body, and up to 100 switching operations per day.
- This is a better controller match than the XKJL1 candidate because the selected coil accepts 24 VDC and has low holding power. XKJL1-40/2 is retained only as an unqualified alternate.
- Rating margin is limited: the EVSE continuous current is 32 A versus a 40 A AC-7a rating. Validate both poles at 32 A and 230 V in the real IP65 enclosure at +55 °C; monitor contactor terminals and automatically derate charging current before unsafe temperature rise.
- The listed −5 °C minimum does not meet the EVSE requirement of −25 °C. The prototype must not be released for cold operation unless pickup, dropout, contact resistance, and mechanical operation pass testing at −25 °C or a qualified alternative is selected.
- Published impulse withstand information is variant-dependent, and no 4000 m rating is provided. Complete insulation-coordination review and high-altitude derating before PCB or enclosure release.
- No built-in auxiliary/mirror contact is shown for the selected 2NO product. Investigate a documented compatible side auxiliary; retain isolated load-side voltage sensing for welded-contact detection.
- Product page: https://baomain.com/products/baomain-dc-ac-modular-contactor-hum-free-bmhc7-40a-2pole ambiguous seller data must be replaced by a controlled manufacturer datasheet before release.

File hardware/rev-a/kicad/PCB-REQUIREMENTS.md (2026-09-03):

# PCB Rev A — placement and routing requirements

## Scope

This PCB contains only the low-voltage EVSE controller. Mains L/N and charging current never enter the PCB. The external assembly contains the breaker, Type A RCD, BRCS aperture conductors, contactor and high-current wiring.

Board target: 160 mm x 90 mm, 2 layers, 1.6 mm FR-4, 1 oz copper for the first controller prototype.

## Zones

| Zone | X range | Purpose |
|---|---:|---|
| A | 5–45 mm | CP/PP and PE-referenced analog interface |
| B | 50–85 mm | BRCS connector and hardwired safety logic |
| C | 90–120 mm | 24 V input and DC/DC power |
| D | 120–160 mm | ESP32-S3, UI and service interfaces |

Maintain an un-routed isolation corridor between the CP/PE-referenced domain and GND_SELV until the grounding architecture is frozen. No copper pour crosses this corridor.

## Placement rules

- ESP32-S3 antenna overhangs or faces the right board edge.
- No copper, vias, display, RFID antenna, cable or enclosure metal in the module antenna keepout.
- J_RDC is near the BRCS cable entry and away from contactor coils and high-current conductors.
- RDC pull-ups, buffers and test points are immediately behind J_RDC.
- Hardware trip path is short and does not pass through the ESP32 area.
- Watchdog and safety latch remain physically separate from UI/Wi-Fi circuits.
- CP TVS and source resistor are adjacent to J_CP_PP.
- Input fuse, reverse-polarity protection and 24 V TVS are adjacent to J_PWR.
- Test points remain accessible after enclosure assembly.
- Four M3 mounting holes have copper and component keepouts.

## Routing rules

- Default signal width: 0.25 mm.
- 24 V and 5 V distribution: at least 0.50 mm, increased after current calculation.
- RDC 5 V supply uses a quiet local route and dedicated return to the LDO.
- CP bipolar output uses a short route with no parallel run beside ESP32 clocks or antenna.
- Hardware trip and watchdog-inhibit nets do not share connectors or routing with LEDs, display or RFID.
- Use continuous GND_SELV plane only inside the SELV region.
- PE-referenced CP region uses its own reference copper until the isolation decision is validated.
- Do not add a GND_SELV-to-PE net tie by convenience.

## Release blockers

- all schematic functional blocks replaced with exact devices and pin numbers;
- controlled BRCS01C-05-H1 connector drawing;
- CP circuit calculation and IEC 61851 threshold review;
- insulation coordination for 4000 m;
- ERC clean with documented exceptions;
- PCB DRC clean;
- antenna and enclosure review;
- thermal review at +55 °C;
- schematic/PCB netlist comparison;
- rendered Gerber inspection.

The draft PCB is for mechanical planning only and must not be fabricated yet.

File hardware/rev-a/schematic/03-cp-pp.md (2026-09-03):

# Sheet 03 — Control Pilot and Proximity Pilot

> Architecture based on OpenEVSE_PLUS v6.5.1 and adapted for ESP32-S3, 3.3 V ADC limits and EU Type 2. See ../../OPENEVSE-ATTRIBUTION.md.

## OpenEVSE reference circuit

The upstream v6.5.1 schematic uses:

- LMV358 on +12 V and a generated negative rail;
- TC1044S charge pump for the negative rail;
- PWM-driven pilot buffer;
- 820 Ω pilot series resistor;
- P6SMB16CA pilot TVS;
- pilot measurement network using 56 kΩ, 100 kΩ and 200 kΩ resistors into a 5 V MCU ADC;
- separate PP_READ input;
- independent relay control, GFCI test and weld-detect signals.

We retain the topology but do not reuse the 5 V ADC divider unchanged.

## CP power rails

- +12V_CP from the protected 24 V input using a regulated converter.
- −12V_CP generated with TC1044S-compatible charge-pump topology only if output-current and temperature calculations pass.
- Local 10 µF and 100 nF capacitors at both rails.
- CP-domain ground/reference strategy must be frozen with the PE/SELV insulation review.

## CP generator

```text
ESP32 CP_PWM (1 kHz)
 -> default-off gate/buffer
 -> LMV358-class amplifier powered from +12V_CP / -12V_CP
 -> 820 Ω OpenEVSE baseline source resistor
 -> P6SMB16CA-class bidirectional protection
 -> Type 2 CP
```

Design requirements:

- approximately +12 V / −12 V waveform;
- State F/unavailable during reset, boot, watchdog fault or safety inhibit;
- duty cycle limited to the configured safe current;
- output short-circuit survival;
- CP output voltage read back independently;
- negative half-cycle/vehicle-diode validation.

The final source resistance must satisfy IEC 61851-1 across amplifier output impedance, resistor tolerance and temperature. The 820 Ω upstream value is a starting point, not an automatic release value.

## 3.3 V CP measurement

The OpenEVSE 5 V sensing network cannot connect directly to ESP32-S3. Preliminary protected divider:

- R_CP_IN = 390 kΩ from CP to CP_SENSE;
- R_CP_BIAS = 82 kΩ from +3V3_A to CP_SENSE;
- R_CP_GND = 120 kΩ from CP_SENSE to GND_A;
- C_CP = DNP initially; select after response-time simulation;
- rail clamps must limit injection current without clipping valid states;
- buffer with a rail-to-rail 3.3 V op-amp or comparator before the ESP32 ADC.

Ideal calculated CP_SENSE is approximately 0.41 V at CP=−12 V and 3.08 V at CP=+12 V. Recalculate with tolerances, clamp leakage, ADC error and CP rail limits before release.

Use comparator windows for safety/state detection; treat the ESP32 ADC as measurement/diagnostics rather than the only state discriminator.

## PP measurement

Adopt OpenEVSE's separate PP_READ concept, adapted for the attached Type 2 cable:

- precision pull-up/reference;
- protected and filtered 3.3 V ADC input;
- thresholds for the actual Type 2 PP resistor values;
- open/short plausibility checks.

Advertised current is the minimum of:

```text
32 A product limit
installation configuration
PP cable limit
thermal derating
local/user limit
remote load-management limit
```

## Protection and validation

- CP and PP protection must survive connector ESD and foreseeable miswiring.
- PE is never fused or switched.
- Validate States A/B/C/D/E/F, diode check, CP short, PP open/short and reset behavior with an EV simulator.
- Validate 1 kHz frequency, duty-cycle accuracy, rise/fall time and voltage levels over −25…+55 °C.
- Do not claim OpenEVSE compatibility or approval; this is an attributed adaptation.

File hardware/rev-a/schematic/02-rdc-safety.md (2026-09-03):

# Sheet 02 — RDC interface and hardwired safety

> This revision uses the public BRCS01C datasheet V1.0.1 behavior for the 5 V version. Production release still requires the controlled datasheet supplied with the purchased BRCS01C-05-H1 lot.

## Confirmed 5 V interface behavior

- VCC is 5 VDC ±3%.
- Pin 2 is AC&DC Trip.
- Pin 4 is CAL.
- Pin 5 is TEST.
- Pin 6 is DC Trip.
- In the normal state the trip outputs pull to GND.
- On the corresponding trip the output changes to high impedance.
- A change from GND to high impedance is also permitted by the product behavior; the controller must treat it as a fault.
- Direct connection of pins 2 or 6 to a relay/contactor is prohibited by the application note.

## Fail-safe trip input channels

RDC_DC_RAW and RDC_ACDC_RAW use separate identical channels:

1. 10 kΩ preliminary pull-up to supervised +3V3, so trip, missing sensor power, or an open signal wire becomes logic high;
2. 1 kΩ preliminary series resistor into a 5 V-tolerant Schmitt buffer/comparator;
3. optional small filter capacitor footprint, DNP until response-time testing;
4. split conditioned output into the hardwired shutdown path and an ESP32 read-only input.

Select the final buffer only after its thresholds are checked against the guaranteed BRCS low-output voltage. Do not wire the two raw outputs together. The hardwired path must not depend on ESP32 execution.

## Set-dominant fault latch

```text
SET = RDC_DC_TRIP
   OR (RDC_ACDC_TRIP AND ACDC_TRIP_ARM)
   OR WATCHDOG_FAULT
   OR RDC_POWER_BAD
   OR CP_HARD_FAULT

RESET = LOCAL_SAFE_RESET
    AND K1_OPEN_CONFIRMED
    AND NOT LOAD_V_PRESENT
```

Requirements:

- SET dominates RESET.
- Power-up defaults to faulted/inhibited.
- ESP32 cannot directly force RESET.
- Loss of logic power removes contactor permission.
- Provide test points on raw trips, conditioned trips, SET, RESET, Q and /Q.

## Hardware contactor permission

```text
K1_HW_ENABLE =
    CONTACTOR_REQUEST
    AND WATCHDOG_OK
    AND RDC_5V_OK
    AND NOT RDC_DC_TRIP
    AND NOT (RDC_ACDC_TRIP AND ACDC_TRIP_ARM)
    AND NOT FAULT_LATCHED
```

The final stage must default OFF while unpowered. K1_HW_ENABLE terminates at J_K1; the future coil driver cannot bypass it.

For the declared installation with an external Type A 30 mA RCD, populate ACDC_TRIP_ARM as DNP/open and use the dedicated DC Trip as the mandatory IEC 62955 shutdown channel. Continue monitoring AC&DC Trip for diagnostics and self-test. The option may be populated only after a separate protection/conformity review.

## Watchdog

U_WD is provisionally TPS3430-Q1.

- Use window mode.
- WDO directly inhibits K1 and sets the latch.
- Only the firmware safety task owns WDI.
- A free-running interrupt must not service WDI.
- Timing components remain DNP until firmware scheduling is frozen.

## TEST and CAL drivers

- **TEST:** drive pin 5 high for 40–100 ms in the first prototype; the public datasheet specifies activation above 40 ms. Use an open-drain or series-buffered driver whose reset state is low.
- **CAL:** pull pin 4 to GND for 50–100 ms using an open-drain transistor. Leave it high impedance otherwise.
- Calibration is allowed only with the contactor open and no current through the sensing aperture.

## RDC self-test

Before every closure request:

1. verify open contactor feedback and no load-side voltage;
2. verify +5V_RDC and inactive raw trips;
3. stimulate TEST for the specified duration;
4. require raw and conditioned transitions;
5. verify K1 permission disappears and the latch sets;
6. release TEST and verify recovery;
7. perform the controlled safe reset;
8. prohibit charging on any missing, late, stuck, or contradictory response.

Production test must inject calibrated AC and smooth-DC residual currents through the aperture and measure total response time.

## Source and remaining blocking evidence

Public sources:

- https://www.bituo-technik.com/news/brcs01c-05-h1-facilitate-designing-a-reliable-built-in-dc-6ma-rcd-at-ac-ev-chargers/
- https://bituo-technik.com/wp-content/uploads/2024/01/TS_BRCS01C_EN_V1.0.1_202312.pdf

Still required before release:

- controlled datasheet and connector drawing supplied for the purchased BRCS01C-05-H1 lot;
- guaranteed output low voltage and sink current;
- exact self-test response-time limits and startup settling time;
- certificate and test-report scope for the exact suffix and harness;
- validation that signal-wire disconnection, loss of 5 V, stuck-low, and stuck-high faults all prohibit charging.

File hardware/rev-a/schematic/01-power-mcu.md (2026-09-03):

# Sheet 01 — Low-voltage power and ESP32-S3

## 24 V input protection

| Ref | Device/value | Connection |
|---|---|---|
| J_PWR | 3-way locking connector | pins per Sheet 00 |
| F1 | 1 A preliminary fuse | series with +24V_IN |
| D1 | SMBJ33A unidirectional TVS | cathode to +24V_PROT, anode to 0V_IN |
| Q_RP1 | 60 V P-channel MOSFET | high-side reverse-polarity protection |
| R_RP1 | 100 kΩ | Q_RP1 gate to source |
| Z_RP1 | 12 V gate-source zener | Q_RP1 gate protection |
| C24_1 | 100 nF, 50 V X7R | +24V_PROT to GND_SELV |
| C24_2 | 47 µF, 50 V | +24V_PROT to GND_SELV |

Final fuse and MOSFET values depend on the future contactor coil and UI load.

## 5.5 V preregulator

Provisional U_BUCK is TPS54360B, a 60 V buck regulator qualified for the required temperature range.

- VIN: +24V_PROT with 2.2 µF and 100 nF local ceramics.
- EN: UVLO divider; preliminary rising threshold 17.5 V.
- BOOT: 100 nF to SW.
- SW: preliminary 22 µH inductor.
- OUT: +5V5_PRE.
- FB: divider calculated for 5.50 V.
- Output: 2 x 22 µF, 10 V X7R plus 100 nF.
- COMP values must be calculated from the final L/C set and verified for loop stability.

## Dedicated RDC rail

| Ref | Part/value | Connection |
|---|---|---|
| U_RDC_LDO | TLV76750 | IN=+5V5_PRE, OUT=+5V_RDC |
| C_RDC_IN | 1 µF X7R | at IN |
| C_RDC_OUT | 4.7 µF X7R | at OUT |
| FB_RDC | 600 Ω @ 100 MHz, rated at least 300 mA | before J_RDC |
| C_RDC_LOCAL1 | 100 nF X7R | sensor side |
| C_RDC_LOCAL2 | 10 µF X7R | sensor side |

The controlled BRCS datasheet remains authoritative for supply tolerance and capacitance.

## 3.3 V rail

Provisional U_3V3 is TPS62133 from +5V5_PRE, with at least 1 A pulse capability.

- 10 µF input capacitor.
- Inductor and output capacitors per final regulator calculation.
- 22 µF plus 100 nF at the ESP32 supply cluster.
- A supervisor prevents partial boot below the validated rail.

## ESP32-S3 module

U1 is ESP32-S3-WROOM-1-N8R8; industrial-temperature suffix must be confirmed.

- 100 nF at every 3.3 V supply pin.
- EN: 10 kΩ pull-up, 1 µF to ground, reset button to ground.
- GPIO0: 10 kΩ pull-up and boot button to ground.
- USB D+/D−: 22 Ω series resistors near U1 and low-capacitance ESD protection.
- RF keepout follows the exact Espressif module drawing.
- Prefer WROOM-1U and an external antenna for a metal distribution cabinet.

## Provisional GPIO map

| Function | GPIO | Reset state |
|---|---:|---|
| CONTACTOR_REQUEST | 4 | pulled low |
| WATCHDOG_WDI | 5 | inactive |
| RDC_TEST_CMD | 6 | inactive |
| RDC_DC_TRIP_SENSE | 7 | defined input |
| RDC_ACDC_TRIP_SENSE | 8 | defined input |
| FAULT_LATCH_SENSE | 9 | defined input |
| K1_AUX_L | 10 | input |
| K1_AUX_N | 11 | input |
| STATUS_LED_DATA | 12 | off |
| LOCAL_BUTTON | 13 | pulled |
| CP_PWM | 14 | off |
| CP_ADC | 15 | input |
| PP_ADC | 16 | input |
| I2C_SDA | 17 | pulled up |
| I2C_SCL | 18 | pulled up |
| USB D− / D+ | 19 / 20 | native USB |
| RFID SPI | 35–38 | inactive |

Allocation remains provisional until display and RFID modules are frozen.

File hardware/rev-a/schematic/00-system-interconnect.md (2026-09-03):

# Sheet 00 — System interconnect (Rev A, Draft 0.2)

> Controller-only design. The power contactor is external and represented by connector J_K1. Do not connect this draft to mains or a vehicle.

## Functional partition

```text
24 V isolated input
  -> input protection
  -> 5.5 V buck -> 5 V RDC LDO -> BRCS01C
                 -> 3.3 V regulator -> ESP32-S3 and logic

Type 2 CP <-> protected CP interface <-> ESP32-S3
Type 2 PP  -> protected PP measurement -> ESP32-S3
BRCS01C    -> hardwired trip latch -> K1_HW_ENABLE
Watchdog   -> hardwired enable chain
```

## External connectors

### J_PWR — isolated controller supply

| Pin | Net | Function |
|---:|---|---|
| 1 | +24V_IN | 18–30 VDC from a certified isolated supply |
| 2 | 0V_IN | supply return |
| 3 | PE | protective earth; not joined to 0V on this sheet |

### J_RDC — BRCS01C-05-H1

| Pin | Net | Function |
|---:|---|---|
| 1 | +5V_RDC | filtered sensor supply |
| 2 | RDC_ACDC_RAW | combined AC/DC trip |
| 3 | GND_RDC | sensor return |
| 4 | RDC_CAL | calibration, reserved |
| 5 | RDC_TEST | self-test control |
| 6 | RDC_DC_RAW | 6 mA DC trip |

Pin order is provisional until checked against the supplied harness drawing.

### J_CP_PP — attached Type 2 cable

| Pin | Net | Function |
|---:|---|---|
| 1 | CP | control pilot |
| 2 | PP | proximity pilot |
| 3 | PE | protective-earth reference |

### J_K1 — future contactor assembly

| Pin | Net | Direction | Function |
|---:|---|---|---|
| 1 | +24V_K1 | out | protected coil feed |
| 2 | K1_CMD_N | out | controlled coil return |
| 3 | K1_AUX_L | in | future L-pole feedback |
| 4 | K1_AUX_N | in | future N-pole feedback |
| 5 | LOAD_V_PRESENT | in | isolated post-contactor voltage detector |
| 6 | GND_SELV | reference | low-voltage return |

The K1 drive stage is intentionally not populated. The safety chain exposes K1_HW_ENABLE; firmware cannot bypass it.

## Mandatory safe states

- ESP32 missing/reset, watchdog timeout, bad RDC supply, active RDC trip, or latched fault forces K1_HW_ENABLE low.
- CP defaults to unavailable until startup self-tests pass.
- Wi-Fi, MQTT, display, RFID, USB, and NTP never participate in the hardwired trip path.

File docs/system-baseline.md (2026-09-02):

# EVSE system baseline — revision 0.1

## 1. Product definition

| Item | Baseline |
|---|---|
| Function | Conductive AC EV supply equipment, Mode 3 |
| Connection | Case C: attached cable and Type 2 vehicle connector |
| Supply | 230 V AC nominal, 50 Hz, L/N/PE |
| Output | 6–32 A configurable; 32 A / 7.4 kW rated |
| Controller | ESP32-S3-WROOM-1 family module running ESP-IDF |
| Network | 2.4 GHz Wi-Fi AP/STA; local web UI, NTP, MQTT |
| Installation | IP20 development configuration and IP65 outdoor-target configuration; wall or pedestal mounting |
| Environment | −25…+55 °C; up to 4000 m altitude |
| Thermal rating | 32 A under qualified conditions; automatic current derating permitted at high temperature/altitude |
| Charging authorization | Local enable initially; remote authorization later |
| Energy control | EVSE advertises maximum current; the vehicle controls actual draw |

The 32 A / 7.4 kW rating is confirmed. The branch circuit, contactor, cable, connector, terminals, PCB conductors, enclosure, and thermal design must all be coordinated with this rating and the applicable installation rules.

## 2. System boundary

```mermaid
flowchart LR
  Grid[230 V grid\nL N PE] --> Protection[Upstream MCB/RCD\nand surge protection]
  Protection --> K1[2-pole power contactor]
  K1 --> Cable[Attached Type 2 cable\nL N PE CP PP]
  Cable --> EV[Vehicle]

  Grid --> PSU[Isolated auxiliary PSU]
  PSU --> Safety[Safety and pilot electronics]
  PSU --> ESP[ESP32 control board]
  Safety -->|CP drive| Cable
  Cable -->|CP measurement| Safety
  Cable -->|PP resistance| Safety
  Grid -->|L/N sensing| Safety
  K1 -->|auxiliary contact| Safety
  RCM[Residual-current monitor] --> Safety
  Temp[Temperature sensors] --> Safety
  Safety -->|hardware enable| KDRV[Contactor driver]
  ESP -->|charge request| KDRV
  KDRV --> K1
  ESP <-->|status/faults| Safety
  ESP <-->|TLS| WiFi[Local/cloud service]
```

The contactor driver uses a two-condition enable: a firmware request **and** a healthy safety chain. Any reset, brownout, watchdog trip, invalid CP condition, residual-current fault, or safety-supply failure removes coil energy.

## 3. External electrical interfaces

### 3.1 High-voltage and connector I/O

| ID | Signal | Direction | Nominal/range | Purpose | Required diagnostics | Safe state |
|---|---|---:|---|---|---|---|
| HV01 | AC_L_IN | Input | 230 V AC | Grid line | presence, RMS, over/undervoltage | isolated from output |
| HV02 | AC_N_IN | Input | neutral | Grid neutral | presence/plausibility | isolated from output |
| HV03 | PE_IN | Passive | protective earth | Protective bonding | continuity concept/TBD installation method | never switched |
| HV04 | AC_L_OUT | Output | 0 or 230 V AC, 32 A max | Vehicle power | voltage before/after switching | de-energized |
| HV05 | AC_N_OUT | Output | neutral, switched by 2-pole contactor | Vehicle return | voltage before/after switching | de-energized |
| HV06 | PE_OUT | Passive | protective earth | Vehicle protective conductor | continuity verification strategy | never switched |
| EV01 | CP | Bidirectional | ±12 V, 1 kHz pilot | connection state/current advertisement | high/low voltage, diode behavior, PWM feedback, short/open | State A/error; contactor open |
| EV02 | PP | Input | resistance to PE in plug/cable | cable current capability | ADC range/open/short/plausibility | conservative limit/no charge |
| EV03 | Cable temperature | Input | sensor-dependent | detect overheated plug/cable termination | open/short/rate/plausibility | derate then stop |

For an attached cable, PP identifies the cable assembly capability and is normally static. The advertised current must be the minimum of product rating, cable rating, site limit, thermal limit, and load-management limit.

### 3.2 Control and low-voltage I/O

| ID | Signal | Direction | Suggested interface | Use | Power-up default |
|---|---|---|---|---|
| CT01 | CP_PWM | Output | timer/PWM into isolated or protected ±12 V driver | 1 kHz current advertisement | disabled / steady +12 V |
| CT02 | CP_HIGH_ADC | Input | protected ADC/comparator | classify CP positive plateau | invalid until qualified |
| CT03 | CP_LOW_ADC | Input | protected ADC/comparator/sample timing | diode/negative plateau test | invalid until qualified |
| CT04 | PP_ADC | Input | protected resistance measurement | cable ampacity | no charge |
| CT05 | CONTACTOR_CMD | Output | GPIO through interlock logic | request coil energization | low |
| CT06 | CONTACTOR_AUX | Input | isolated auxiliary feedback | open/closed/weld detection | unknown/fault until read |
| CT07 | RCM_FAULT | Input | isolated, preferably latched | AC/DC residual-current trip | trip asserted until test passes |
| CT08 | RCM_TEST | Output | certified module test input | startup/periodic self-test | inactive |
| CT09 | LINE_SENSE_IN | Input | reinforced-isolated sensing | input supply present | unknown |
| CT10 | LINE_SENSE_OUT | Input | reinforced-isolated sensing | output/weld detection | unknown |
| CT11 | COIL_CURRENT | Input | ADC/comparator, optional | driver/coil plausibility | zero expected |
| CT12 | TEMP_POWER | Input | NTC/RTD front end | contactor/terminal temperature | invalid until sampled |
| CT13 | TEMP_PCB | Input | NTC/internal sensor | electronics temperature | invalid until sampled |
| CT14 | SERVICE_BUTTON | Input | debounced GPIO | commissioning/local stop | inactive |
| CT15 | STATUS_LED | Output | RGB driver | user state/fault indication | off or fault pattern |
| CT16 | UART_SERVICE | Bidirectional | isolated/service-only header | factory diagnostics | disabled in enclosure |

### 3.3 Communications and data

| Interface | Initial scope | Safety authority |
|---|---|---|
| Wi-Fi | provisioning, local status, configuration, logs, OTA | none; commands pass through local safety/state validation |
| HTTPS/MQTT | optional authenticated telemetry/control | none |
| NVS | limits, calibration, counters, fault history | corrupted data selects conservative defaults/no charge |
| OTA | dual-image update with rollback | update only while contactor is open; failure cannot energize output |

## 4. Protection and self-checking

### 4.1 Hardware protections

1. Upstream overcurrent protection sized for the installation and conductor rating.
2. Residual-current protection coordinated with local installation requirements. Use either appropriate Type B protection or Type A protection combined with an IEC 62955-compliant 6 mA DC residual-current detecting device, subject to the final conformity design.
3. Two-pole power contactor rated for the applicable utilization, fault level, endurance, temperature, and 32 A continuous current.
4. Contactor auxiliary feedback plus isolated output-voltage sensing to detect failure to open or close.
5. Protective-earth conductor is continuous and never switched. PE monitoring must not create a hazardous touch current or defeat installation protection.
6. Reinforced isolation/clearance/creepage between mains/pilot domains and user/network-accessible SELV electronics.
7. Coil suppression, surge protection, input filtering, fusing of auxiliary circuits, and thermal protection.
8. Hardware gating causes the contactor to drop out without relying on the main application task.

### 4.2 Startup test sequence

| Step | Test | Pass condition | Failure action |
|---:|---|---|---|
| 1 | Reset cause and watchdog | known reset source; counters valid | log; latch if repeated |
| 2 | Program/configuration integrity | valid application and configuration CRC/signature | inhibit charging |
| 3 | RAM/peripheral sanity | required peripherals initialize | inhibit charging |
| 4 | GPIO safe-state readback | contactor command low | inhibit/latch |
| 5 | Contactor-open confirmation | auxiliary=open and no unexpected output voltage | weld fault; latch |
| 6 | Input-supply check | voltage/frequency within configured limits | wait/inhibit |
| 7 | Residual-current monitor test | certified test completes in allowed time | latch fault |
| 8 | CP analog self-test | generated levels and measurement channels plausible | inhibit charging |
| 9 | PP and temperature plausibility | sensors in physical ranges | inhibit or conservative limit |
| 10 | Communications initialization | may fail without affecting safety | charge locally if policy permits |

### 4.3 Continuous diagnostics

- Sample CP synchronously and require stable classification with debounce/hysteresis.
- Compare commanded CP duty with measured duty and plateaus.
- Check the EV diode signature before energizing the contactor.
- Monitor residual current using a protection path with the required response independent of network operation.
- Compare contactor command, auxiliary contact, coil current, and output voltage.
- Monitor supply voltage, current, power, and temperature; apply warning, derating, then shutdown thresholds.
- Run task and hardware watchdogs; a missed deadline removes the hardware enable.
- Detect ADC stuck-at, open/short sensors, impossible combinations, excessive rates of change, and stale samples.
- Store the first fault cause, relevant measurements, state, and monotonic timestamp before later cascade faults overwrite context.

## 5. Charging control algorithm

### 5.1 Current-limit calculation

```text
I_advertised = min(
    I_product_rating,
    I_cable_PP,
    I_site_configuration,
    I_thermal_limit,
    I_load_management,
    I_user_or_backend_limit
)
```

If the result is below 6 A, suspend charging by using the standard pilot behavior rather than advertising a non-standard sub-6 A value. For the normal IEC 61851 PWM region, the commonly used relationship is `Imax = duty_percent × 0.6 A` from 10% through 85%; higher-duty behavior must be implemented from the licensed standard and validated during compliance testing.

### 5.2 CP state interpretation

The approximate nominal positive CP plateaus below are useful design targets, not production acceptance limits. Exact thresholds, tolerances, timing, and special states must come from the controlled edition of IEC 61851-1.

| State | Approx. positive CP | Meaning | Contactor |
|---|---:|---|---|
| A | +12 V | no vehicle | open |
| B | +9 V | vehicle connected, not requesting energy | open |
| C | +6 V | vehicle requests energy | may close after all checks |
| D | +3 V | vehicle requests energy with ventilation requirement | open unless ventilation is supported |
| E | 0 V | short/error | open, fault |
| F | −12 V | EVSE unavailable/error indication | open |

This prototype does not support forced ventilation, so State D shall not energize the contactor.

### 5.3 State machine

```mermaid
stateDiagram-v2
  [*] --> BootSafe
  BootSafe --> SelfTest: outputs forced safe
  SelfTest --> AvailableA: all mandatory tests pass
  SelfTest --> FaultLatched: safety test fails
  AvailableA --> ConnectedB: stable State B + valid diode/PP
  ConnectedB --> AvailableA: unplug
  ConnectedB --> ChargingC: State C + authorization + valid limits + safety healthy
  ChargingC --> ConnectedB: EV stops request / local suspend
  ChargingC --> AvailableA: unplug sequence
  ChargingC --> FaultLatched: safety trip or switching mismatch
  ConnectedB --> FaultLatched: CP/RCM/internal fault
  AvailableA --> FaultLatched: internal/RCM/weld fault
  FaultLatched --> SelfTest: power cycle or authorized reset after cause removed
```

### 5.4 Closing sequence

1. Confirm stable State C, valid diode result, valid PP, authorization, and at least 6 A available.
2. Confirm RCM healthy, temperatures acceptable, input supply valid, contactor reported open, and output not unexpectedly energized.
3. Apply valid CP PWM for the computed current limit.
4. Assert the safety-chain enable and contactor request.
5. Within a bounded time, require auxiliary=closed and output voltage present; otherwise open and latch a switching fault.
6. Enter Charging only after feedback agrees. Continue every diagnostic while charging.

### 5.5 Opening sequence

1. Remove the contactor request immediately for a safety fault; use controlled suspension timing only for ordinary scheduling/load management where permitted.
2. Require auxiliary=open and output de-energized within bounded times.
3. A closed auxiliary or persistent output voltage is a welded-contactor fault: latch it, mark the connector hazardous, and do not automatically retry.
4. Return CP to the appropriate connected/available behavior only when safe.

## 6. Preliminary electronic architecture

Use separate schematic sheets/functional blocks:

1. **Mains entry:** L/N/PE terminals, fuse/MCB interface, surge suppression, EMI filter, isolated voltage sensing.
2. **Power switching:** 2-pole contactor, auxiliary contact, coil driver, hardware shutdown gate, output-voltage sensing.
3. **Residual-current protection:** certified RDC-DD/RCM module with fault and test interfaces.
4. **Control pilot/proximity pilot:** protected ±12 V CP source, 1 kHz PWM switching, high/low sampling, PP resistance input.
5. **Auxiliary power:** certified isolated AC/DC supply plus protected 12 V/5 V/3.3 V rails, brownout supervision.
6. **Controller:** ESP32 module, watchdog/supervisor, isolated sensing interfaces, service header, status UI.
7. **Metering/thermal:** isolated energy-metering IC or certified meter interface, current sensor, NTC inputs.

The original ESP32 can be used for the prototype, but select a current module revision that supports the required security features and has adequate lifecycle availability. Keep antenna clearance and high-current/mains circuitry far from the RF section.

## 7. Firmware architecture

| Component | Responsibility | Must not do |
|---|---|---|
| Safety supervisor | validate hardwired faults, watchdogs, contactor feedback; own final enable | depend on Wi-Fi |
| CP service | PWM generation, synchronized ADC capture, state/diode classification | close contactor directly |
| Charging state machine | legal transitions, authorization, start/stop sequencing | bypass safety supervisor |
| Limit manager | calculate minimum current constraint and PWM request | advertise above any constraint |
| Measurement service | filtered voltage/current/power/energy/temperature | make unvalidated safety decisions alone |
| Network service | provisioning, authenticated API, telemetry, time | directly write actuator GPIOs |
| Configuration service | schema, bounds, CRC/version migration | accept unsafe out-of-range limits |
| Fault recorder | first-fault snapshot and persistent event log | erase latched faults remotely without policy |
| Update manager | signed A/B OTA and rollback | update while output is energized |

Use ESP-IDF rather than an Arduino-only architecture for explicit task watchdogs, OTA rollback, secure storage, TLS, partition control, and production security options.

## 8. Fault classes

| Class | Examples | Recovery |
|---|---|---|
| Transient inhibit | no Wi-Fi when policy requires it, undervoltage, current allocation below 6 A | automatic after stable normal condition |
| Charge-session fault | CP invalid, overtemperature shutdown, contactor failed to close | unplug or explicit local reset after cause clears |
| Latched safety fault | residual current, welded contactor, safety-chain failure, corrupted safety configuration | de-energize; service/power-cycle policy after inspection |
| Permanent/service | repeated self-test failure, calibration invalid, incompatible hardware | service required |

Remote software may reduce current or stop charging. It may not clear welded-contactor, residual-current, PE-related, or internal safety faults without the defined local/service procedure.

## 9. Verification plan

Before connecting a vehicle, build a CP/PP simulator and isolated mains test fixture. Verify at minimum:

- every CP state, boundary, diode missing/reversed, CP short to PE, and noisy transitions;
- PP values, open/short, and advertised-current clamping;
- reset/brownout/watchdog at every state and during contactor transition;
- RCM startup test, injected AC/DC residual-current faults, and stuck fault/test lines;
- contactor fails to close, fails to open, welded contacts, missing auxiliary feedback, and false output sensing;
- over/undervoltage, sensor failures, overtemperature/derating, and current-limit changes;
- Wi-Fi loss, malformed commands, authentication failure, configuration corruption, OTA interruption, rollback;
- conducted/radiated emissions pre-compliance, EFT/burst, surge, ESD, insulation, dielectric strength, earth continuity, touch current, temperature rise, and abnormal operation.

No test that deliberately introduces a hazardous mains fault should be performed without a reviewed fixture, upstream protection, emergency isolation, and qualified personnel.

## 10. Standards register (to be confirmed for the exact EU market)

- IEC 61851-1:2017 plus Corrigendum 1:2023 — general requirements and Mode 3 control.
- IEC 62196-2 — Type 2 dimensional/interchangeability requirements.
- IEC 62955:2018 — residual DC detecting devices for Mode 3 EVSE.
- IEC 60364-7-722 — low-voltage installation requirements for EV supplies.
- IEC 61439-7 and/or the applicable product assembly standard, depending on construction and conformity route.
- IEC 61000 family and applicable product EMC standard(s).
- EU Low Voltage, EMC, Radio Equipment, RoHS, and other applicable legislation; determine harmonized standards and conformity route with a competent laboratory before freezing the design.

Standards must be purchased/accessed through an authorized source. This document intentionally does not substitute for their normative limits and test procedures.

## 11. Open decisions before schematic capture

1. RFID technology and credential policy.
2. Touch-display size, technology, and interface.
3. Phone application scope: responsive local web app/PWA or separately distributed native app.
4. Whether OCPP is required later; it is not part of revision 0.1.
5. Exact upstream MCB, Type A RCD, SPD, prospective fault current, and installation coordination assumptions.

The external C32 circuit breaker and Type A 40 A / 30 mA RCD are installation equipment, not EVSE schematic or BOM components.

## 12. Next engineering deliverables

1. Freeze the above decisions and create traceable system requirements.
2. Perform hazard analysis/FMEA and allocate each safety requirement to hardware, firmware, installation, or certified protection device.
3. Select the contactor, attached cable/plug, RCM/RDC-DD, power supply, metering method, and isolation components.
4. Calculate isolation coordination, thermal rise, conductor sizing, protection coordination, and switching endurance.
5. Capture schematics and simultaneously build the CP/PP low-voltage simulator.
6. Implement the firmware state machine against simulator tests before enabling mains switching.

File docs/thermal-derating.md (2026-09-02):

# Thermal derating algorithm — revision 0.1

## 1. Objective

The EVSE is rated up to 32 A, but automatic current reduction is permitted when temperature, installation, or altitude reduces safe continuous-current capability. The algorithm protects the cable terminations, contactor, power wiring, PCB, auxiliary supply, and enclosure while avoiding rapid current oscillation.

This document defines algorithm structure. Numerical temperature thresholds remain provisional until the selected components, sensor positions, enclosure, mounting configuration, and thermal-test results are available.

## 2. Required temperature channels

| Channel | Location | Purpose | Mandatory |
|---|---|---|---:|
| T1 | L input/output terminal or hottest power terminal | detect loose/high-resistance connection and conductor heating | yes |
| T2 | contactor body near the main contacts | protect contactor and estimate power-path heating | yes |
| T3 | control/power PCB hot region | protect PSU, drivers, metering, and controller | yes |
| T4 | internal enclosure air | estimate ambient-to-internal rise and improve derating stability | recommended |
| T5 | display/UI compartment | protect LCD/touch assembly in IP65 model | recommended |

The selected Type 2 plug has no embedded temperature sensor. Protection therefore depends on a qualified 32 A cable/plug assembly, correct PP coding, internal sensing, installation controls, and conservative thermal validation.

## 3. Sensor validation

Each channel has a raw value, filtered value, timestamp, validity state, and diagnostic flags. Before use, verify:

- ADC/reference and supply are within range;
- sensor is not open or shorted;
- value is inside the physically possible range;
- sample is fresh;
- rate of change is plausible, except where a real rapid thermal fault remains possible;
- related sensors are reasonably consistent without assuming they must be equal.

A mandatory invalid sensor inhibits a new session. During charging it initiates an immediate controlled stop, unless a separately justified independent hardware trip already guarantees a faster safe response. It shall not silently substitute a fixed 32 A allowance.

## 4. Per-sensor current envelope

Each sensor `i` produces a permissible current `Ithermal_i` from a validated, monotonic non-increasing curve:

```text
if T_i <= Tderate_start_i:
    Ithermal_i = 32 A

if Tderate_start_i < T_i < Tstop_i:
    Ithermal_i = interpolate(validated thermal curve for sensor i)

if T_i >= Tstop_i:
    Ithermal_i = 0 A and thermal shutdown
```

The combined thermal limit is:

```text
Ithermal = min(Ithermal_T1, Ithermal_T2, Ithermal_T3, ...)
```

The charge-current advertisement remains:

```text
Iadvertised = min(
    32 A product rating,
    cable PP rating,
    installation/site limit,
    Ithermal,
    load-management limit,
    user/backend limit
)
```

Never round upward. Quantize downward to the supported CP duty/current step after applying all limits.

## 5. Preliminary state behavior

```mermaid
stateDiagram-v2
  [*] --> Normal
  Normal --> Derating: any sensor exceeds its derate threshold
  Derating --> Normal: all sensors below release thresholds for cooldown time
  Derating --> Suspended: permissible current below 6 A
  Derating --> ThermalFault: any sensor reaches stop threshold
  Normal --> ThermalFault: rapid/severe overtemperature
  Suspended --> Derating: permissible current at least 6 A after cooldown
  Suspended --> ThermalFault: temperature continues rising
  ThermalFault --> ReadyAfterReset: all sensors below restart thresholds and local/session reset policy satisfied
  ReadyAfterReset --> Normal: new authorized session
```

Rules:

1. A required reduction is applied without waiting for the normal current-increase timer.
2. Current increases are slow and stepwise, and only after all relevant temperatures remain below their release thresholds for the configured cooldown time.
3. Use separate derate-entry and derate-release thresholds or equivalent hysteresis.
4. If `Ithermal < 6 A`, suspend: stop the energy-transfer sequence, open the contactor, and apply the applicable IEC 61851 pilot behavior. Do not advertise less than 6 A.
5. A stop-threshold crossing is a thermal session fault, not an ordinary load-management suspension.
6. Following thermal shutdown, automatic contactor reclosure within the same session is prohibited. Recovery requires cooldown plus the defined user/unplug/reset policy.
7. Network loss, NTP changes, display failure, or MQTT commands cannot disable derating.

## 6. Altitude treatment

Altitude is a product configuration/installation constraint, not a live sensor unless an appropriate pressure sensor is intentionally added. Validate thermal performance for the worst allowed 4000 m condition or derive a conservative altitude-dependent maximum-current table.

Possible implementation after testing:

```text
Iinstallation_max = min(Isite, Ialtitude_table, Ienclosure_variant, Imounting_variant)
```

The IP20/IP65 and wall/pedestal configurations may have different qualified limits. Configuration identifiers shall be fixed by manufacturing/service data and shall not be freely editable through MQTT or the normal user interface.

## 7. Provisional software timing policy

Exact values require test validation. Initial development values may be used only for simulator and bench work:

- thermal task period: 100–500 ms;
- mandatory sample stale timeout: no more than a few task periods;
- reduction confirmation: short filtering sufficient to reject ADC noise but not sustained heating;
- current increase: no faster than 1 A per defined multi-second interval;
- cooldown before increase: several minutes of stable temperature;
- restart after thermal shutdown: longer stable cooldown plus session reset.

These are architecture targets, not production safety values.

## 8. Thermal validation matrix

Test each relevant enclosure and mounting configuration at representative supply voltage and 6, 16, 25, and 32 A:

| Variable | Required coverage |
|---|---|
| Ambient | −25 °C startup, room temperature, elevated points through +55 °C |
| Altitude/cooling | 4000 m equivalent or justified correlated method |
| Enclosure | IP20 and sealed IP65 |
| Mounting | wall and pedestal |
| Solar load | include if outdoor installation permits direct sun |
| Supply | tolerance extremes relevant to coil, PSU, and dissipation |
| Faults | loose/high-resistance termination, blocked thermal path, sensor open/short/stuck |

Record temperatures at terminals, contactor contacts/body, cable entry, conductors, PCB hot spots, PSU, RDC-DD, display, enclosure surface, and each installed sensor. Derive thresholds from the lowest applicable component/material limit with measurement error, production tolerance, aging, and safety margin.

## 9. Acceptance criteria

- No monitored or unmonitored safety-relevant component exceeds its justified limit.
- Advertised-current reduction matches the calculated minimum limit and never increases during worsening temperature.
- The vehicle-facing CP update remains standards-compliant.
- Below 6 A permissible current, the contactor opens and the EVSE suspends safely.
- Every sensor fault produces the specified inhibit/stop response.
- No oscillation occurs around derating thresholds.
- Recovery cannot bypass cooldown, fault policy, or the safety supervisor.

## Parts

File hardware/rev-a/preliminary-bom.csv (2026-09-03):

Item | Reference | Manufacturer | Part number | Description | Qty | Status | Key requirement
1 | U1 | Espressif | ESP32-S3-WROOM-1-N8R8 | Wi-Fi MCU module 8MB flash 8MB PSRAM | 1 | Selected | Final suffix and temperature grade audit
2 | U2 | Texas Instruments | TPS3430-Q1 | Independent window watchdog VSON-10 | 1 | Provisional | Timing component calculation required
3 | U3 | BITUO Technik | BRCS01C-05-H1 | 5V AC/DC residual current sensor 6mA DC | 1 | Preferred | Certificate and controlled datasheet required
4 | U4 | Texas Instruments | TPS54360B | 60V buck regulator configured for 5.5V | 1 | Provisional | Calculate compensation UVLO EMC thermal and transient margins
5 | U5 | Texas Instruments | TLV76750 | Low-noise 5V LDO for RDC sensor | 1 | Provisional | Verify dropout stability ripple and temperature
6 | U6 | Texas Instruments | TPS62133 | 3.3V regulator for ESP32-S3 | 1 | Provisional | Calculate inductor capacitors Wi-Fi transient and thermal margin
7 | U7 | TBD | TBD | Power supervisor and safety logic | 1 | Open | Independent fail-safe gating
8 | Q1 | TBD | DNP | Future contactor coil switching device | 1 | Postponed | Select after exact coil and permitted suppression are known
9 | Q2 | TBD | TBD | Dominant RDC trip gate-clamp transistor | 1 | Open | Size from guaranteed BRCS output
10 | D1 | TBD | DNP | Future contactor coil suppression network | 1 | Postponed | Select only from coil manufacturer data and release-time test
11 | K1 | Baomain | BMHC7-40 2NO DC/AC24V | 2-pole 40A AC-7a modular contactor with 2W electronic coil | 1 | Preferred prototype candidate | Cold limit is -5C; verify -25C operation 4000m insulation aux contact certifications and hot-enclosure derating
12 | J3 | TBD | TBD | Keyed locking 6-way RDC connector | 1 | Open | Must match BRCS01C-05-H1 harness
13 | J4 | TBD | TBD | 4-way contactor coil and auxiliary connector | 1 | Open | Current voltage temperature locking
14 | FB1 | TBD | TBD | Ferrite bead for RDC 5V supply | 1 | Open | Impedance and DC current after EMC testing
15 | C_RDC1 | TBD | TBD | RDC local ceramic decoupling | 1 | Open | Value per BITUO datasheet
16 | C_RDC2 | TBD | TBD | RDC local bulk decoupling | 1 | Open | Value per BITUO datasheet
17 | R_GS | TBD | TBD | Q1 gate-source pull-down | 1 | Open | Guarantee off state and discharge time
18 | D_ESD_USB | TBD | TBD | Low-capacitance USB ESD protection | 1 | Open | IEC 61000-4-2 system target
19 | J_USB | TBD | TBD | USB service connector for IP20 only | 1 | Open | Not populated/exposed in IP65
20 | LED1-LED3 | TBD | TBD | Status LEDs or addressable status indicator | 1 set | Open | Patterns distinguishable without color alone
21 | SW1 | TBD | TBD | Sealed local button | 1 | Open | IP65 system rating and lifecycle

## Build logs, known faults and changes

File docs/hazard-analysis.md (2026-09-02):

# Preliminary hazard analysis and design FMEA — revision 0.1

## 1. Method

This is an early design-driving analysis, not a certification risk assessment. Scores use:

- Severity **S**: 1 negligible, 2 minor, 3 serious, 4 life-threatening/fire.
- Occurrence **O**: 1 remote, 2 occasional, 3 probable, 4 frequent before controls.
- Detection **D**: 1 almost certain detection, 2 likely, 3 difficult, 4 unlikely before harm.

Any severity-4 item requires explicit design treatment. Scores must be revisited after parts, schematics, construction, and test data exist.

## 2. Hazard register

| ID | Hazard / initiating fault | Potential effect | S | O | D | Required controls | Verification evidence | Residual status |
|---|---|---|---:|---:|---:|---|---|---|
| H-001 | Contactor welded closed | Type 2 plug remains energized when charging should stop | 4 | 2 | 2 | 2-pole rated contactor; auxiliary feedback; output-voltage sensing; latched fault; prominent indication; no retry | Welded-contact fault injection and output-sense tests | Open |
| H-002 | Contactor closes without valid vehicle request | Exposed energized contacts, arcing, vehicle damage | 4 | 2 | 2 | Normally-off coil; hardware safety gate; valid C state plus diode; state-machine ownership; feedback timing | Reset/glitch/state-transition fault injection | Open |
| H-003 | ESP32 freezes with coil commanded on | Charging continues without supervision | 4 | 2 | 2 | External/hardware watchdog or safety supervisor; retriggered enable; RCM direct trip; fail-open driver | Freeze each safety task and CPU; verify dropout | Open |
| H-004 | Residual AC/DC current is not interrupted | Electric shock; upstream Type A RCD may be blinded by DC | 4 | 2 | 3 | Conformity-appropriate RCD/RDC-DD; direct hardware trip; startup/periodic test; fault latch | Calibrated residual-current injection and self-test failure | Open |
| H-005 | PE conductor open/high resistance | Exposed conductive parts/vehicle may become hazardous during another fault | 4 | 2 | 3 | Robust PE path; bonding; strain relief; earth-continuity production test; installation requirements; monitoring strategy subject to earthing system | PE resistance, pull/strain, single-fault assessment | Open |
| H-006 | L/N reversal, PEN presented to EVSE, or unsupported earthing topology | Protection/sensing assumptions invalid; touch-voltage risk | 4 | 2 | 3 | Support TN-S/TN-C-S only with separate L/N/PE at input; prohibit internal PEN split; installation instructions; switch L and N | Wiring fault matrix and installation review | Open |
| H-007 | CP circuit falsely classifies State C | Contactor energizes at wrong time | 4 | 2 | 2 | Protected CP front end; independent comparator/ADC plausibility; stable thresholds/timing; diode check; measured PWM feedback | CP boundary/noise/open/short/diode tests | Open |
| H-008 | Advertised current exceeds cable/site/product limit | Overheating, breaker operation, fire | 4 | 2 | 2 | Minimum-of-all-limits algorithm; PP validation; hard 32 A maximum; bounded config; PWM readback | Limit combinations and corrupt-config tests | Open |
| H-009 | Loose terminal or degraded contact | Local overheating/fire below overcurrent trip | 4 | 3 | 3 | Rated terminals; torque/process controls; temperature sensor placement; derating/shutdown; thermal design margin | Temperature-rise and loose-connection abnormal test | Open |
| H-010 | Cable/plug overheats or is mechanically damaged | Burn/fire/shock | 4 | 2 | 3 | Certified 32 A cable/plug; strain relief; temperature monitoring if available; inspection guidance; current derating | Cable pull/flex and temperature-rise tests | Open |
| H-011 | Contactor fails to close or chatters | Contact damage, overheating, unstable charging | 3 | 2 | 2 | Coil supply supervision; auxiliary and output feedback; bounded transition; minimum retry policy; undervoltage lockout | Low-coil-voltage and feedback fault tests | Open |
| H-012 | Output voltage sensor reports safe falsely | Welded contact not recognized | 4 | 2 | 3 | Auxiliary feedback diversity; input/output correlation; startup test; sensor diagnostics | Stuck-at/open/short injection | Open |
| H-013 | Auxiliary supply brownout/reset during charging | Undefined GPIO or contactor chatter | 4 | 2 | 2 | Supervisors; GPIO pull-down; fail-open gate; coil hold-up/dropout design; reset-cause logging | Supply ramp/dip/interruption tests | Open |
| H-014 | Temperature sensor fails low | Thermal protection unavailable | 4 | 2 | 3 | Open/short diagnostics; dual/location diversity where justified; rate and cross-sensor plausibility | Sensor substitution/fault injection | Open |
| H-015 | Conducted/radiated disturbance corrupts control | Unexpected switching, reset, incorrect readings | 4 | 2 | 3 | Filtering, isolation, layout, shielding, watchdogs, debounce, safe reset | ESD/EFT/surge/RF immunity pre-compliance | Open |
| H-016 | Surge damages driver into energized failure | Contactor energized or control isolation compromised | 4 | 2 | 3 | Coordinated SPD; coil suppression; isolation; failure-mode review; fuse/protection | Surge and destructive component analysis | Open |
| H-017 | Water/condensation reaches hazardous circuits | Shock, tracking, corrosion, fire | 4 | 2 | 3 | Define IP/environment; drainage/vent strategy; spacing/coating as justified; environmental tests | IP, humidity, condensation assessment | Open |
| H-018 | Wi-Fi attacker issues charge/config/update commands | Unauthorized use or unsafe current configuration | 3 | 3 | 2 | Authenticated local API; TLS; unique credentials; bounded limits; signed OTA; no direct actuator commands | Security review and penetration tests | Open |
| H-019 | Malformed/corrupted firmware or OTA | Loss of function or unsafe behavior | 4 | 2 | 2 | Secure boot/signatures; rollback; update only de-energized; watchdog; safe boot state | Interrupted/tampered OTA and rollback tests | Open |
| H-020 | Flash/configuration corruption | Wrong current, thresholds, or safety policy | 4 | 2 | 2 | CRC/version; strict bounds; redundant critical values where justified; no-charge defaults | Bit-flip/corrupt-partition tests | Open |
| H-021 | Meter/current sensor under-reads | Overcurrent/overload not recognized by software | 4 | 2 | 3 | Upstream hardware overcurrent protection; sensor plausibility/calibration; product maximum independent of reading | Sensor gain/stuck-at tests | Open |
| H-022 | User unplugs under load | Arcing/contact wear | 3 | 2 | 2 | Correct CP response and contactor-opening sequence; connector conformity; timing validation | Disconnect tests at representative current | Open |
| H-023 | State D accepted without ventilation | Charging in unsafe ventilation condition | 4 | 1 | 1 | Explicit state-machine prohibition and test | State D simulation | Open |
| H-024 | Safety fault automatically clears repeatedly | Re-energization into persistent hazard | 4 | 2 | 2 | Fault-class policy; latched severe faults; limited retries; first-fault log; local/service reset | Repeated-fault scenario tests | Open |
| H-025 | Incorrect service wiring/test procedure | Shock or equipment damage during development/service | 4 | 2 | 3 | Touch-safe fixture; upstream isolation/protection; discharge verification; procedures; qualified operators | Fixture and procedure review | Open |
| H-026 | Reduced air dielectric strength at 4000 m | Insulation breakdown, tracking, shock, or fire | 4 | 2 | 3 | Apply altitude correction to clearances; review component insulation ratings; dielectric test with justified equivalent conditions | Insulation-coordination calculation and dielectric verification | Open |
| H-027 | Reduced cooling at altitude or +55 °C ambient | Contactor, terminals, cable, PSU, or enclosure overheats | 4 | 3 | 3 | Worst-case thermal model; high-temperature components; sensor placement; current derating; full-load thermal test | +55 °C chamber and 4000 m-equivalent thermal verification | Open |
| H-028 | IP65 display/button/RFID interfaces leak | Water ingress causes corrosion, shock, false inputs, or fire | 4 | 2 | 3 | Qualified sealed interfaces; gasket compression control; drainage/vent strategy; assembled-product IP test | IP65, humidity, thermal-cycle, and condensation tests | Open |
| H-029 | Pedestal movement, impact, or cable pull | Enclosure damage, conductor strain, loss of PE continuity | 4 | 2 | 3 | Pedestal structural design; anchoring specification; cable strain relief; PE routing margin; impact/pull testing | Mounting, impact, pull, and earth-continuity tests | Open |

## 3. Mandatory independent safety paths

The schematic shall demonstrate these paths without relying on Wi-Fi or a healthy application task:

1. Residual-current fault → hardware gate disabled → contactor coil de-energized.
2. Watchdog/supervisor timeout → hardware gate disabled → contactor coil de-energized.
3. Brownout/auxiliary-power loss → contactor driver defaults off.
4. Application reset/bootloader/OTA state → contactor request defaults off.
5. Local severe overtemperature trip should have a hardware shutdown path if analysis shows firmware-only response is insufficient.

## 4. Safety validation priorities

The first prototype test fixture shall prioritize H-001 through H-009 and H-013. Vehicle testing is prohibited until those fault responses have objective evidence and an independent schematic/test review is complete.

## 5. Decisions blocking risk reduction

- PE-monitoring approach within the confirmed TN-S/TN-C-S scope.
- Indoor/outdoor environmental target and IP rating.
- Exact upstream Type A RCD/MCB ratings and the integrated RDC-DD topology.
- Contactor feedback architecture and selected contactor.
- Cable plug temperature sensing is unavailable; thermal safety must not depend on it.
- Installation fault current, overvoltage category, pollution degree, and 4000 m altitude correction.

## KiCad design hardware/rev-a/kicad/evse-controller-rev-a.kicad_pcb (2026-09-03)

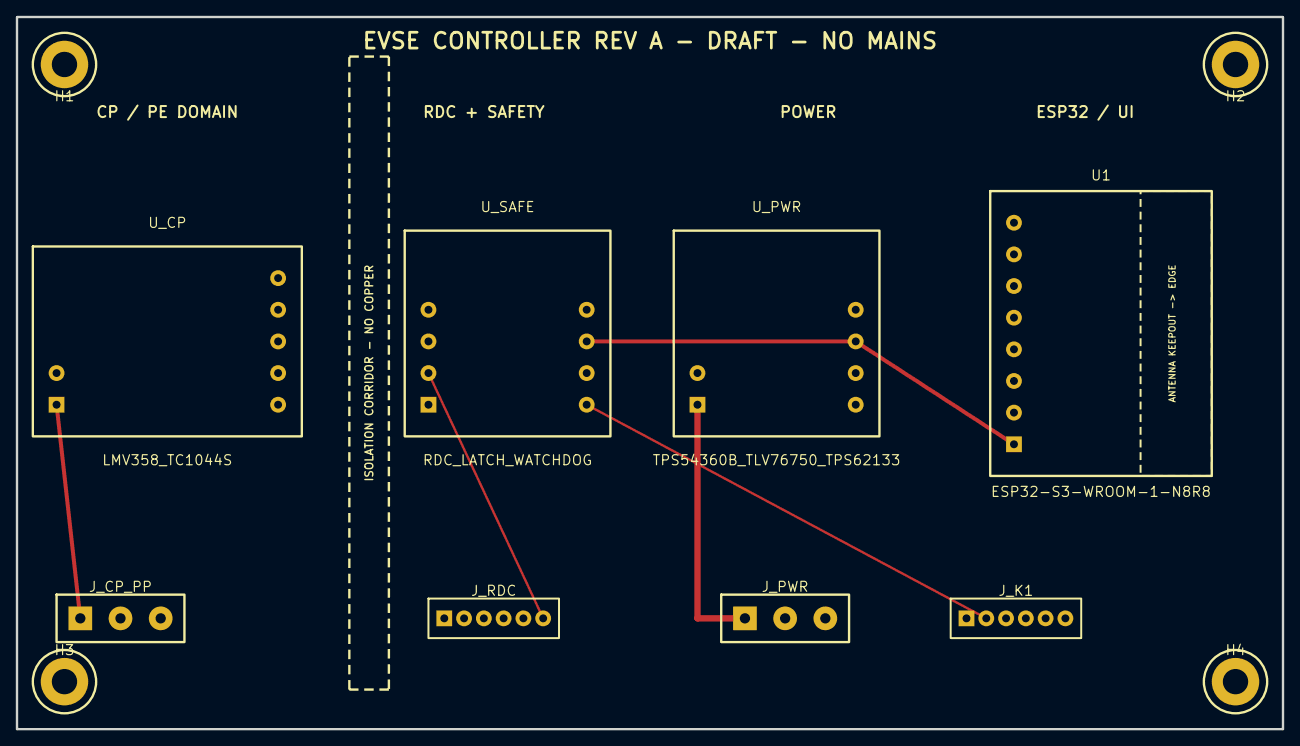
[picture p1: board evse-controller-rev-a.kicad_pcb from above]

Board: 2 copper layers, 160.0 x 90.0 mm, 12 parts (0 on the bottom side), 17 nets.

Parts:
H1, H2, H3, H4: M3_Mount
J_CP_PP: Terminal_1x3_5.08
J_K1: JST_1x6
J_PWR: 24V_IN; Terminal_1x3_5.08
J_RDC: JST_1x6
U1: ESP32-S3-WROOM-1-N8R8; ESP32_S3_MODULE
U_CP: LMV358_TC1044S; CP_ANALOG_BLOCK
U_PWR: TPS54360B_TLV76750_TPS62133; POWER_BLOCK
U_SAFE: RDC_LATCH_WATCHDOG; SAFETY_BLOCK

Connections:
+3V3: U1.1, U_CP.5, U_PWR.5, U_SAFE.7
+5V_RDC: J_RDC.1, U_PWR.4
+24V_IN: J_PWR.1, U_PWR.1
+24V_PROT: J_K1.1, U_CP.7, U_PWR.2
CP: J_CP_PP.1, U_CP.1
CP_PWM: U1.3, U_CP.3
CP_SENSE: U1.4, U_CP.4
GND_SELV: J_K1.6, J_PWR.2, J_RDC.3, U1.2, U_CP.6, U_PWR.6, U_SAFE.8
K1_AUX_L: J_K1.3, U1.7
K1_AUX_N: J_K1.4, U1.8
K1_HW_ENABLE: J_K1.2, U_SAFE.5
PE: J_CP_PP.3, J_PWR.3
PP: J_CP_PP.2, U_CP.2
RDC_ACDC_RAW: J_RDC.2, U_SAFE.1
RDC_CAL: J_RDC.4, U1.6, U_SAFE.4
RDC_DC_RAW: J_RDC.6, U_SAFE.2
RDC_TEST: J_RDC.5, U1.5, U_SAFE.3

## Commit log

2026-09-03 Start Rev A controller schematic specification
2026-09-03 Add preliminary Rev A controller BOM
    [preliminary-bom.csv]
2026-09-03 Add XKJL1-40/2 candidate to preliminary BOM
    [preliminary-bom.csv]
2026-09-03 Select BMHC7-40 as conditional prototype contactor
2026-09-03 Update K1 BOM to BMHC7-40 24V AC/DC
    [preliminary-bom.csv]
2026-09-03 Add low-voltage power and ESP32 schematic definition
2026-09-03 Add RDC and hardwired safety schematic definition
2026-09-03 Add CP and PP schematic architecture
2026-09-03 Split controller schematic from future contactor stage
2026-09-03 Select provisional controller regulators and postpone K1 driver
    [preliminary-bom.csv]
2026-09-03 Define fail-safe BRCS01C 5V trip and test interface
2026-09-03 Add initial KiCad controller schematic
    [evse-controller-rev-a.sch]
2026-09-03 Document KiCad schematic status and import procedure
2026-09-03 Mark KiCad draft as OpenEVSE-based adaptation
    [evse-controller-rev-a.sch]
2026-09-03 Add visual preview of current controller schematic
2026-09-03 Define Rev A PCB floorplan and routing requirements
2026-09-03 Add preliminary Rev A KiCad PCB floorplan
    [evse-controller-rev-a.kicad_pcb]

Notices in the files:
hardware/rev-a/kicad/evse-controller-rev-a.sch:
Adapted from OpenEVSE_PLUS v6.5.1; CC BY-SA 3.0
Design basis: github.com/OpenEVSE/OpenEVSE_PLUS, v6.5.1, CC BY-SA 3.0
